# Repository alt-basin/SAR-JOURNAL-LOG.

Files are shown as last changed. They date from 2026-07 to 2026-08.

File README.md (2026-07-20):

# Sensor-Controlled Thermal Mapping for Search and Rescue Operations (SCOUT) 

**Editor's Note**

- This project is still a work in progress. Software development has not yet begun. While I have studied how the hardware components interface with one another, I have not yet started the implementation phase. My current priority is designing the custom PCB. Since the PCB layout depends on the exact physical dimensions of the drone frame and its components, obtaining the hardware is a necessary first step to ensure accurate measurements, footprints, and component placement.

  If you have any questions or suggestions regarding the project, feel free to reach out. As development progresses, I will publish the PCB design files, complete development logs, and software documentation in this repository for others to reference, learn from, or reuse. All project materials will be openly shared with proper attribution. The PCB design will also include my personal signature as a mark of authorship.

**For Forge Reviewers**

- I hope the components listed in the Bill of Materials (BOM) can be funded so I can verify their physical dimensions before completing the PCB design. This will help ensure accurate footprints, proper component placement, and minimize alignment issues during assembly.

  I will cover the cost of PCB fabrication myself and will upload the completed PCB design files to this GitHub repository once they are finalized.

**Current Status**

* Learning and implementing an Extended Kalman Filter (EKF)
* Researching autonomous navigation and localization methods
* Preparing documentation and development logs

---

  ### PROJECT OVERVIEW:
#### Main Description

- The goal of this project is to develop a prototype autonomous-capable Search and Rescue (SAR) drone intended for outdoor disaster scenarios such as earthquakes, landslides, and floods.

  The system is designed to assist search operations by capturing aerial data and detecting heat signatures using a thermal camera. This capability may help identify potential heat sources associated with human presence in outdoor environments with reduced visibility, including nighttime conditions, smoke, or partially obstructed areas.

  The drone combines thermal imaging, optical flow, an Inertial Measurement Unit (IMU), and distance sensors to support stable flight and estimate its motion during operation. The project serves as a demonstration of how low-cost robotic aerial systems can contribute to SAR-oriented exploration, environmental monitoring, and situational awareness.

#### Reason for Build

- This project originated from hardware that was initially intended for a larger cargo-drone design being developed for a future robotics competition. During the planning stage, it became apparent that the selected components were not suitable for the intended cargo-drone requirements.

   Rather than discarding or selling the components, the decision was made to repurpose them into a Search and Rescue drone prototype that could also serve as a school research project.

   The project provides an opportunity to gain practical experience in drone development, autonomous navigation, sensor integration, state estimation, and embedded systems while making effective use of existing hardware resources.

---

### HARDWARE OVERVIEW:
#### Hardware list:
*sensor + electronics selection:*
<table border="1" cellpadding="10" cellspacing="0" style="border-collapse: collapse; width: 100%; font-family: Arial, sans-serif;">
  <thead>
    <tr style="background-color: #1a1a2e; color: white;">
      <th>Component</th>
      <th>Function</th>
      <th>Purpose in the Project</th>
      <th>Link</th>
    </tr>
  </thead>
  <tbody>
    <tr>
      <td><strong>ICM-20602</strong></td>
      <td>Measures linear acceleration and angular velocity using a 3-axis accelerometer and 3-axis gyroscope.</td>
      <td>Provides orientation and motion data for flight stabilization, attitude estimation, and autonomous navigation.</td>
      <td><a href="https://shopee.ph/product/1541768712/47054536700" target="_blank">View Product</a></td>
    </tr>
    <tr style="background-color: #f2f2f2;">
      <td><strong>PMW3901</strong></td>
      <td>Tracks the movement of the ground beneath the drone using optical flow technology.</td>
      <td>Estimates horizontal velocity and position, allowing stable flight in GPS-denied indoor environments.</td>
      <td><a href="https://shopee.ph/product/1538176896/43426280197" target="_blank">View Product</a></td>
    </tr>
    <tr>
      <td><strong>VL53L1X</strong></td>
      <td>Uses a laser Time-of-Flight (ToF) system to accurately measure the distance to nearby surfaces.</td>
      <td>Maintains altitude, enables vertical positioning, and assists in autonomous takeoff and landing.</td>
      <td><a href="https://shopee.ph/product/1032050598/22974977435" target="_blank">View Product</a></td>
    </tr>
    <tr style="background-color: #f2f2f2;">
      <td><strong>MLX90640BAA</strong></td>
      <td>Captures a 32×24 thermal image by measuring infrared radiation emitted from objects.</td>
      <td>Detects heat signatures, performs thermal mapping, and assists in locating people or heat sources during search-and-rescue operations.</td>
      <td><a href="https://shopee.ph/product/1622086447/43117260078" target="_blank">View Product</a></td>
    </tr>
    <tr>
      <td><strong>ESP32-S3-WROOM-1 (N16R8)</strong></td>
      <td>Processes sensor data, executes control algorithms, and manages communication between all hardware components.</td>
      <td>Acts as the drone's primary controller, performing sensor fusion (EKF), flight control, autonomous navigation, telemetry, and system coordination.</td>
      <td>—</td>
    </tr>
  </tbody>
</table>

*Airframe and Power System*
<table border="1" cellpadding="10" cellspacing="0" style="border-collapse: collapse; width: 100%; font-family: Arial, sans-serif;">
  <thead>
    <tr style="background-color: #1a1a2e; color: white;">
      <th>Component</th>
      <th>Function</th>
      <th>Purpose in the Project</th>
      <th>Link</th>
    </tr>
  </thead>
  <tbody>
    <tr>
      <td><strong>JMT X4 310mm Frame</strong></td>
      <td>Provides the structural framework for mounting and protecting all electronic and mechanical components.</td>
      <td>Serves as the drone's main chassis, ensuring stability, durability, and proper component placement during flight.</td>
      <td><a href="https://shopee.ph/product/936939040/18971876269" target="_blank">View Product</a></td>
    </tr>
    <tr style="background-color: #f2f2f2;">
      <td><strong>Uangel X2807 1300KV Motor</strong></td>
      <td>Converts electrical energy into rotational motion to spin the propellers and generate thrust.</td>
      <td>Provides the lift and maneuverability required for stable flight, navigation, and autonomous operation.</td>
      <td><a href="https://shopee.ph/product/53025630/22476350635" target="_blank">View Product</a></td>
    </tr>
    <tr>
      <td><strong>55A 4-in-1 ESC</strong></td>
      <td>Controls the speed and direction of each brushless motor by regulating electrical power from the battery.</td>
      <td>Enables precise motor control for stable flight, attitude correction, and autonomous maneuvers.</td>
      <td><a href="https://shopee.ph/product/709543365/28338653787" target="_blank">View Product</a></td>
    </tr>
    <tr style="background-color: #f2f2f2;">
      <td><strong>6S 5200mAh 60C LiPo Battery</strong></td>
      <td>Supplies electrical power to the motors, flight controller, sensors, and other onboard electronics.</td>
      <td>Acts as the drone's primary power source, providing sufficient energy for flight operations and autonomous missions.</td>
      <td>—</td>
    </tr>
    <tr style="background-color: #f2f2f2;">
      <td><strong>PRO MINI560</strong></td>
      <td> is a <strong>DC-DC buck converte</strong> that efficiently reduces a higher input voltage to a stable lower output voltage for electronic devices.</td>
      <td>Acts as the drone's primary power source, providing sufficient energy for flight operations and autonomous missions.</td>
      <td><a href="https://shopee.ph/product/1400942760/28687044552" target="_blank">View Product</a></td>
    </tr>
    <tr style="background-color: #f2f2f2;">
      <td><strong>7040 Gemfan Tri-Blade</strong></td>
      <td> Converts the motor's rotational force into thrust, allowing the UAV to generate lift and maneuver during flight.</td>
      <td> Provides stable and efficient lift for the SCOUT UAV while carrying its onboard sensors and thermal camera during autonomous missions.</td>
      <td>—</td>
    </tr>
  </tbody>
</table>

#### Schematic:

<table>
  <tr>
    <!-- Left Column -->
    <td width="55%" valign="top">

<h2>Hardware Connections</h2>

<table>
  <thead>
    <tr>
      <th>Component</th>
      <th>Connection</th>
    </tr>
  </thead>
  <tbody>
    <tr>
      <td><strong>VL53L1X</strong></td>
      <td>SDA → GPIO 8<br>SCL → GPIO 9</td>
    </tr>
    <tr>
      <td><strong>MLX90640BAA</strong></td>
      <td>SDA → GPIO 8<br>SCL → GPIO 9</td>
    </tr>
    <tr>
      <td><strong>ICM-20602</strong></td>
      <td>SAO/SDO → GPIO 13<br>SDA/SDI → GPIO 11<br>SCL/SPC → GPIO 12</td>
    </tr>
    <tr>
      <td><strong>PMW3901</strong></td>
      <td>MISO → GPIO 13<br>CLK → GPIO 12<br>MOSI → GPIO 11<br>CS → GPIO 10</td>
    </tr>
    <tr>
      <td><strong>45A 4-in-1 ESC</strong></td>
      <td>
        M1 → GPIO 4<br>
        M2 → GPIO 5<br>
        M3 → GPIO 6<br>
        M4 → GPIO 7<br>
        GND → IN−<br>
        VCC → IN+
      </td>
    </tr>
  </tbody>
</table>

> **Note:** The VL53L1X and MLX90640BAA share the same I²C bus (GPIO 8 & 9), while the ICM-20602 and PMW3901 share the SPI bus (GPIO 11–13).

</td>

<!-- Right Column -->
<td width="45%" align="center" valign="top">



<br><br>

<i>Figure 1. Current hardware wiring diagram.</i>

</td>
</tr>
</table>

[Drone Schematic](SCHEMATIC/GENERAL.SCHEMATIC.v1.png)

---

### SYSTEM OVERVIEW:

#### Perception system:

- This subsystem provides the drone’s perception and navigation capability for indoor search and rescue mapping. It combines motion sensing, position estimation, altitude measurement, and thermal imaging to allow controlled flight and environmental scanning in a confined area (2m × 2m).
  
<table>
    <thead>
        <tr>
            <th>Component</th>
            <th>Type</th>
            <th>Purpose</th>
        </tr>
    </thead>
    <tbody>
        <tr>
            <td>ICM-20602</td>
            <td>IMU (Inertial Measurement Unit)</td>
            <td>Will be used as the sensor to determine the drone’s yaw, roll, and pitch, as well as its movement using the built-in accelerometer.</td>
        </tr>
        <tr>
            <td>PMW3901</td>
            <td>Optical Flow Sensor</td>
            <td>Will be used to determine the drone’s velocity in mid-air.</td>
        </tr>
        <tr>
            <td>VL53L1X + lid</td>
            <td>Time-of-Flight (ToF) Distance Sensor</td>
            <td>This will serve as the main sensor for measuring the drone’s altitude. However, this sensor is weaker outdoors, so testing and demonstrations will be conducted indoors.</td>
        </tr>
        <tr>
            <td>MLX90640BAA</td>
            <td>Thermal Infrared Camera</td>
            <td>This will be used to capture thermal images for mapping the environment.</td>
        </tr>
  </tbody>
</table>

#### **Control system:**

&emsp; *closed-loop system:*
- This part of the the subgroup measures the raw output of the sensors and filters them, allowing for smooth control.
<table>
    <thead>
        <tr>
            <th>Component</th>
            <th>Kalman Filter Category</th>
            <th>Reason</th>
        </tr>
    </thead>
    <tbody>
        <tr>
            <td>ICM-20602</td>
            <td>Extended Kalman Filter (EKF)</td>
            <td>Provides acceleration and angular velocity measurements used to predict the drone's state. Required for nonlinear attitude estimation.</td>
        </tr>
        <tr>
            <td>PMW3901</td>
            <td>Extended Kalman Filter (EKF)</td>
            <td>Provides optical flow used to correct velocity estimates. Depends on altitude and orientation, making the model nonlinear.</td>
        </tr>
        <tr>
            <td>VL53L1X</td>
            <td>Extended Kalman Filter (EKF)</td>
            <td>Provides range measurements for altitude estimation. Requires tilt compensation (roll/pitch), making the measurement nonlinear.</td>
        </tr>
        <tr>
            <td>MLX90640</td>
            <td>Not part of EKF</td>
            <td>Used for thermal imaging and environment mapping. Operates independently from state estimation.</td>
        </tr>
    </tbody>
</table>

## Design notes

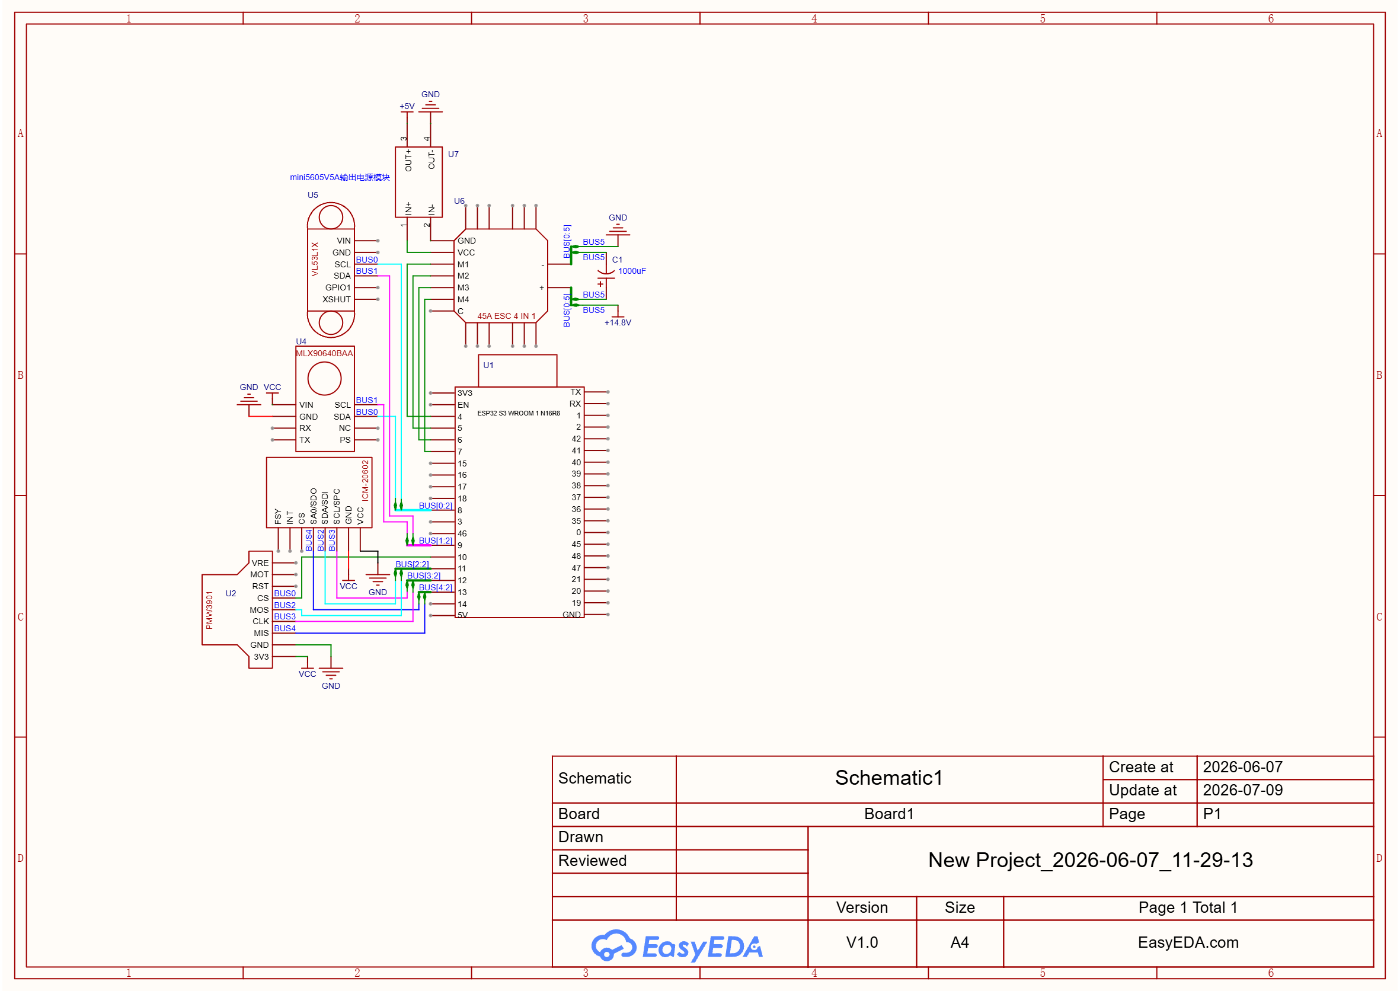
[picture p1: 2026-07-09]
SCH_Schematic1_1-P1_2026-07-09.png

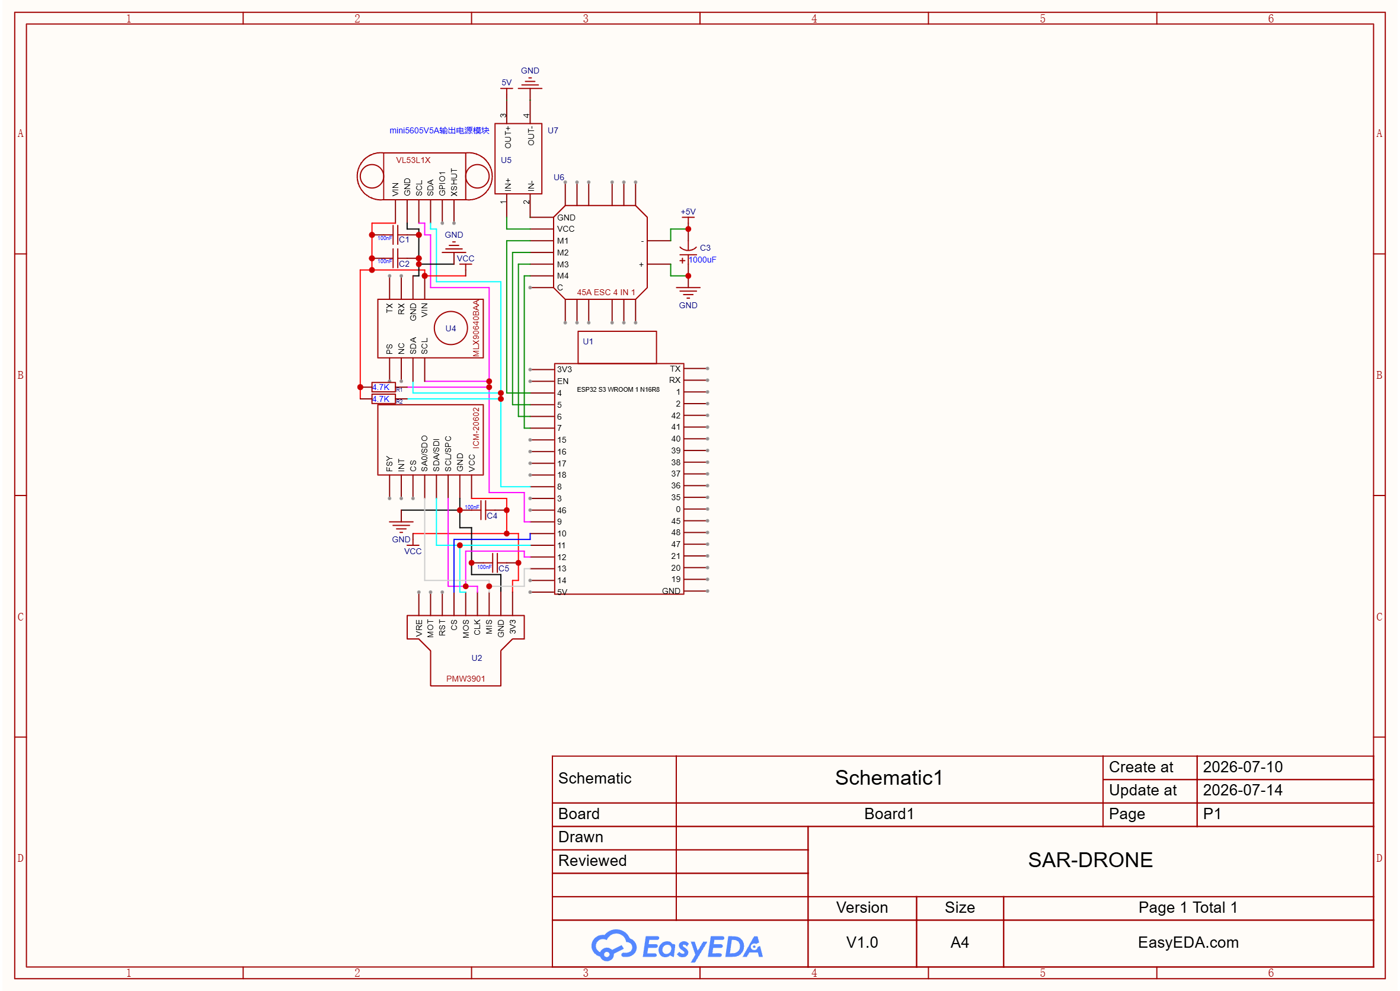
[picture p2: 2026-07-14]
SCHEMATIC/GENERAL.SCHEMATIC.V1.png

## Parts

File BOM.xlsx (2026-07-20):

Component | Quantity | Retail price | Link
ICM-20602 | 1 | 294 | https://shopee.ph/product/1541768712/47054536700
PMW3901 | 1 | 412 | https://shopee.ph/product/1538176896/43426280197
VL53L1X + LID | 1 | 408 | https://shopee.ph/product/1032050598/22974977435
MLX90640BAA | 1 | 2375 | https://shopee.ph/product/1622086447/43117260078
55A ESC 4-IN-1 | 1 | 1545 | https://shopee.ph/product/709543365/28338653787
PRO MINI560 - 5V | 1 | 105 | https://shopee.ph/product/1137847711/24580460137
Uangel X2807 1300kv (4x) | 1 | 2380 | https://shopee.ph/product/779642846/25478721198
 | Total: | 7519.00

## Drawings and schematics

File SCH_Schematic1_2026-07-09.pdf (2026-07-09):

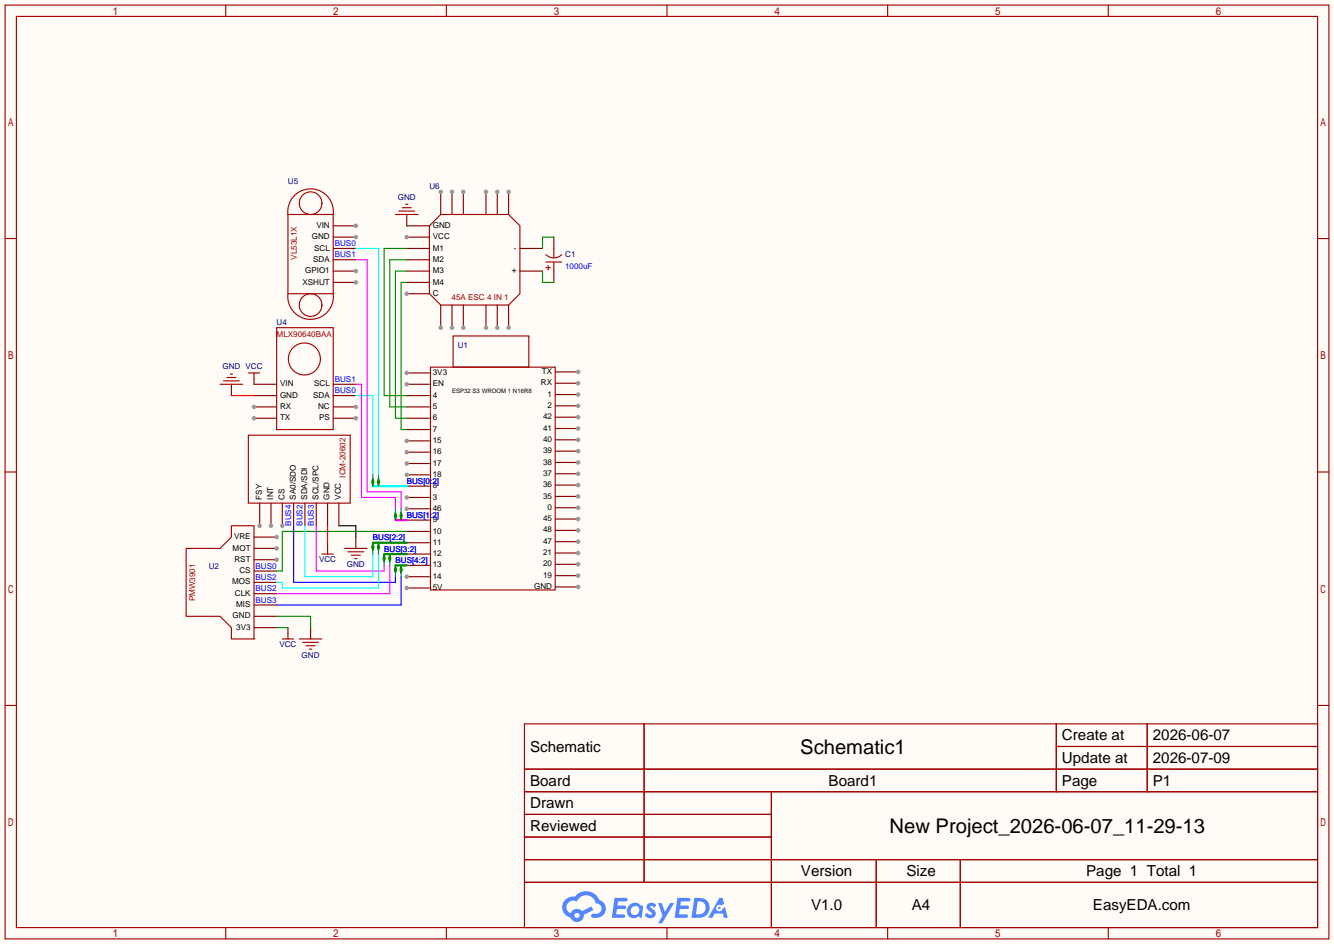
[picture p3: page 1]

Schematic | Schematic1 | Create at | 2026-06-07

Update at | 2026-07-09

Board | Board1 | Page | P1
Drawn | | New Project_2026-06-07_11-29-13
Reviewed

Version | Size | Page 1 Total 1
V1.0 | A4 | EasyEDA.com

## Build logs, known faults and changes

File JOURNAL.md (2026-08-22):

# DEVLOG #001: INTRODUCTION

 **Total Time Spent: 5 minutes** pre-repo work
 
 first ever log for the drone, i have already created the schematic, though i will need to continue creating the <br> drones
 pcb to hold the parts which may take a long time. So lets start by discussing the parts of the drone.

  im currently using a 
   - JMT X4 310MM X4M310L
   - Uangel X2807 1300Kv
   - 6s 5200mah XT60

7df4a46b-1eed-4ec3-b51c-5aaf73f997b2
e7acb897-12b7-4c4b-9561-0c1f1995207d

---
# DEVLOG #002: INTRO TO SCHEMATIC

 **Total Time Spent: 1 hour** pre-repo work

   ### SENSORS:
   
  - Below me is the schematic for the drone, which includes the parts needed for it to be full automated, so lets start one by one.
    for this dorone i will be using a ESP32-S3-WROOM-N16R8-1 as the flight control, and i will be using a 45A esc 4-in-1.
    
 
 
<table>
    <thead>
        <tr>
            <th>Component</th>
            <th>Type</th>
            <th>Purpose</th>
            <th>Link</th>
        </tr>
    </thead>
    <tbody>
        <tr>
            <td>MPU-6050</td>
            <td>IMU (Inertial Measurement Unit)</td>
            <td>Measures angular velocity and acceleration for estimating the drone's orientation and movement.</td>
            <td><a href="https://shopee.ph/product/580325202/25288429666">Product Link</a></td>
        </tr>
        <tr>
            <td>PMW3901</td>
            <td>Optical Flow Sensor</td>
            <td>Measures relative ground movement to estimate horizontal velocity and position changes.</td>
            <td><a href="https://shopee.ph/product/1538176896/43426280197">Product Link</a></td>
        </tr>
        <tr>
            <td>VL53L1X + Lid</td>
            <td>Time-of-Flight (ToF) Distance Sensor</td>
            <td>Measures the distance to the ground, providing altitude data for low-altitude indoor flight.</td>
            <td><a href="https://shopee.ph/product/1032050598/22974977435">Product Link</a></td>
        </tr>
        <tr>
            <td>MLX90640BAA</td>
            <td>Thermal Infrared Camera</td>
            <td>Captures thermal images for heat-source detection and thermal environment mapping.</td>
            <td><a href="https://shopee.ph/product/56540719/23154817594">Product Link</a></td>
        </tr>
        <tr>
            <td>45A 4-in-1 ESC</td>
            <td>Electronic Speed Controller</td>
            <td>Controls the speed of the brushless motors and distributes power from the battery.</td>
            <td><a href="https://shopee.ph/product/933050849/26220013460">Product Link</a></td>
        </tr>
        <tr>
            <td>4S 3200mAh 60C LiPo</td>
            <td>Lithium Polymer Battery</td>
            <td>Supplies electrical power to the drone's flight and sensing systems.</td>
            <td><a href="https://shopee.ph/product/1729536151/57358540563">Product Link</a></td>
        </tr>
    </tbody>
</table>

---
# DEVLOG #003: DRONE FRAME 

 **Total Time Spent: 17 minutes** 

 - The drone frame assembly was completed after the M3 nuts arrived. Below is a showcase of the finished frame from multiple angles.
  
  c05a2e44-0346-4d8f-9d85-8e693a4ecb37
51f45b0d-6c06-419b-8082-c667ce248333
b290c748-67dc-41cf-a960-94b504ee50dd

---
# DEVLOG #004: INTRODUCTION FOR BMI323

 **Total Time Spent: 5 minutes**

 - I decided to switch from the MPU6050 to a better IMU, the BMI323. This is mainly because it has lower drift and improved overall performance. I also considered using an ICM-series IMU, but most online stores currently do not have it available.

- The main difference between the two is their sensor performance and accuracy, which includes improvements in noise levels, stability, and motion tracking reliability in the BMI323 compared to the MPU6050. 

| Feature | MPU6050 | BMI323 |
| --- | --- | --- |
| Gyro noise density | ~0.005–0.01 °/s/√Hz | ~0.003 °/s/√Hz (lower = better) |
| Accelerometer noise | ~400 µg/√Hz | ~80–120 µg/√Hz |
| Gyro range | ±250 to ±2000 °/s | ±125 to ±2000 °/s (configurable, cleaner output) |
| Accelerometer range | ±2g to ±16g | ±2g to ±16g |
| Bias instability (gyro drift) | ~10–20 °/hr (worse in practice) | ~2–5 °/hr (much better) |
| Output resolution | 16-bit | 16–24 bit effective processing |
| Sample rate | up to 1 kHz | up to 6.4 kHz (depends config) |
| Power consumption | ~3.9 mA | ~0.8–1.5 mA (more efficient) |



---
# DEVLOG #005: NEW SYMBOL AND SCHEMATIC

**Total Time Spent: 10 minutes**

 - So i just created the new schematic for the drone which included the new IMU (BMI323).
   so the reason why I didnt do this yesterday is because i had assignments, and also i was lazy.

   it took around 4 mins to create the new symbol for the imu since i was trying to find the exact board model
   in a datasheet though i found the model by a youtube video. Which also described how to use it.

  
  

https://github.com/alt-basin/SAR-JOURNAL-LOG./blob/main/Schematics%2BPCB/Schematic_drone.pdf

---

# DEVLOG #006: MEASUREMENTS FOR PCB

**Total Time Spent: 26 mins 28 seconds**

- I decided to measure the drone frame (shown below) so I can use it as a reference for the PCB's shape, which will host the ESP32-S3-WROOM-1, IMU (Inertial   Measurement Unit), and other components.

  Right now, I am only preparing the measurements for the PCB since it will be mounted directly onto the frame. I am also waiting for the sensors to arrive so I can measure their pin layouts and dimensions accurately. I believe it is better to rely on measurements taken from the actual physical components rather than using dimensions from online sources.

  Here are the measurements.

  34cc6814-a46b-4476-9909-0267edcaa080
  341fd21e-3ca5-4c1e-b4bd-874106287189

 - I just wanted to show this to you since I currently have assignments to work on, and I won't be able to create the <br> actual measurements in a 3D model yet. I may have to work on it during the weekend.

---

# DEVLOG #007: UPDATE FOR REPO AND NEW SENSOR

**Total Time Spent: 1 hour 29 mins 54 seconds**

- So since I dont have any assignments today, i decided to create a data table for each sensor. So you could know whats the capabilities, while doing so I realized that my current imu (which is BMI323), is weak. Not that its fully weak but for testing that uses autonomous programming, this would be a problem.

  Then i asked gpt for potential sensors that are better than the current (BMI323) and recommended me to use and ICM-42688-P, which is better over all. The main problem wasnt cost as i have it covered, the main problem is the market availability. Each shopping app basically have this type of sensor, the problem was that it was all out of stock.

**6:27 pm**

- I was talking with Gpt about the sensors to find the common and cheapest, which landed me on the ICM-20602. so comparing this with the current bmi323, here are the data table. Now even though it may just be like a point different from a bmi, i only want to switch as the bmi323 isnt really popular.

  now that i have decided what kind of sensor i will use, i should probably change the BOM first, then i will start on creating the new schematic again.
  i should probably just add the data tables for the sensors tommorow.

| Specification | BMI323 |  | ICM-20602 |
|---|---|---|---|
| Sensor Type | 6-Axis IMU | = | 6-Axis IMU |
| Accelerometer Range | ±2g, ±4g, ±8g, ±16g | = | ±2g, ±4g, ±8g, ±16g |
| Gyroscope Range | **±125, ±250, ±500, ±1000, ±2000 °/s** | > | *±250, ±500, ±1000, ±2000 °/s* |
| Resolution | 16-bit | = | 16-bit |
| Gyro Noise Density | *~0.007 °/s/√Hz* | < | **0.004 °/s/√Hz** |
| Accel Noise Density | *~180 µg/√Hz* | < | **100 µg/√Hz** |
| Max Gyro ODR | *6.4 kHz* | < | **8 kHz** |
| Max Accel ODR | **6.4 kHz** | > | *4 kHz* |
| FIFO Size | **2 KB** | > | *1 KB* |
| Interfaces | **SPI, I²C, I3C** | > | *SPI, I²C* |
| Supply Voltage | **1.71–3.6 V** | > | *1.71–3.45 V* |
| Power Consumption | **Lower** | > | *Higher* |
| Package Size | **2.5 × 3.0 mm** | > | *3.0 × 3.0 mm* |
| Release Era | **Modern** | > | *Older* |
| Drone Usage | *Limited* | < | **Widely Used** |
| ESP32 Compatibility | Yes | = | Yes |

28f02160-13c6-4550-bb51-76e5383b8505

**8:05 pm**

- Here is the thing the schematic. i only keep chagning the schematic so i could have a visual guideline for the pcb.




https://github.com/alt-basin/SAR-JOURNAL-LOG./blob/main/BOM.xlsx <br>
https://github.com/alt-basin/SAR-JOURNAL-LOG./blob/main/SCHEMATIC/SCHEMATIC.pdf

- hello its me again, now im not actually saying that the ICM 20602 is better than the BMI323, just that the specs arent really built for an automated drone. Even though the bmi wins by 8 that doesnt automatically guarentee that the imu its great. just that its for other projects not for mine.

---

# DEVLOG #008: FOOTPRINT

**Total Time Spent: 4 hours**

 - Hello! It's been a while since my last update because I've been swamped with schoolwork. During my free time, I decided to work on creating the PCB footprints for the custom board I'm designing.

   At the moment, the PCB isn't fully complete. I still need to add the through-hole solder pads so the board can be connected to the components properly. I wasn't able to accurately track the total amount of time I spent on this task since I was constantly switching between EasyEDA and Google Docs for documentation and planning. However, I'd estimate that I spent around **4 hours** working on it.




 - so probably im just going to add this to the pcb development file, but soon i will replace it with a more refined version with the through-hole solder pads.
   I re-synced all of my project files and didn't realize it would reset their timestamps.

   also be minded this is my first time making a footprint, so i dont really know if its bad or not

---

# DEVLOG #009: idk

**Total Time Spent: 10 mins**

- While working on my PCB design yesterday, I realized that I had been using copper traces instead of the board outline. I corrected that mistake, so here's the updated version.

   I'm also writing today's devlog a bit earlier because I forgot to do it yesterday, and I really want to get to sleep early since I only got around three hours of sleep. I also had to attend the birthday celebration of a family friend today, which took up most of my evening.
   
   
   
   <br>
   
   

- also, pcbdoc.

---

# DEVLOG #010: SCHEMATIC REFINING

**Total time spent: 4 mins**

- I also updated the schematic by adding a Mini560 buck converter. This allows the ESC to supply a stable regulated voltage to the microcontroller instead of powering it directly from the battery. The buck converter steps down the battery voltage to a level that is safe for the microcontroller and other low voltage electronics, improving the reliability and safety of the power distribution system.



---

# DEVLOG #011: Motor Mounting Issue and Assembly Lesson

**Total time spent: 3 Minute**

5b88c2b6-0f94-4790-9b57-e16fb2b95f28

*Figure X. Example of motor winding damage observed after assembly.
This image shows one example of the damage found on the brushless motors. While this motor shows visible copper wire damage, several other motors exhibited deeper cuts that were difficult to properly capture through photography due to their location and severity.*

- For future iterations, motor mounting depth will be checked before installation, and appropriate screw lengths will be selected to prevent interference with internal components.

  During the early assembly phase of the drone prototype, the motor mounting screws used were found to be longer than required. This caused the screws to contact the internal motor components, resulting in visible damage to the copper winding area of the brushless motors.

  Initial inspection was performed by comparing the phase resistance of each motor using a multimeter. The readings remained consistent across the motors, indicating that electrical continuity was maintained. However, this incident highlighted the importance of verifying hardware dimensions and screw length before mechanical assembly.

# DEVLOG #012: ADDRESSING THE DELAY

**Total time spent: 3 Minutes**

- Hello! The reason progress on the robot has been slower than expected is that I've been working on a detailed project analysis that will be reviewed by my teacher as part of my research project.

  Since my groupmates are not very experienced with robotics, I considered switching to a simpler project, the smartwatch prototype, which would require less complex programming. However, that project also presents a challenge. Its primary function is detecting hazardous gases, such as carbon monoxide, so I need to build a proof of concept by testing the sensors. To do that properly, I need to consult with an engineer from our main campus.

  Because of this, I am currently preparing the project overview and technical analysis to compare both projects and determine which one is the most feasible to pursue for our research.

  

---

# DEVLOG #013: HEADSUP

**Total time spent: 1 Minute**

- Hello again, just be reminded I had to re-sync the entries because i had to add parsed time "Total time spent: 3 Minutes", since i thought it should be "duration: ". okay good bye.

  

---

# DEVLOG #014: FENDERS FOR THE DRONE

 **Total time spent: 34 Minutes 23 Seonconds**
 
**6:32 pm**




*Figure X shows an example of Joseph Fraser's prop guard design. This design is particularly useful during testing because it helps protect the propellers from accidental impacts with walls, obstacles, or other objects during indoor flight. It also improves safety by reducing the risk of damage to both the drone and its surroundings, making it well suited for prototype development and testing.*

- Hello! A while back, while working on my SAR drone, I realized that the entire research is mainly intended for indoor use. Because of that, I decided that adding prop guards would make the drone much safer during testing.

  At first, I planned to design and create my own prop guards. However, after considering my current schedule, I realized that it would take time away from more important parts of the project. I still need to revise the research paper, especially since the project overview will be reviewed by an engineer, so I want to make sure I use my time wisely.

  Because of this, I decided to use an open source prop guard design instead. This allows me to focus on completing the drone itself while still improving safety for indoor operation.

  The prop guard design I will be using was created by **Joseph Fraser**. You can find it here:

https://www.printables.com/model/465552-7-75-inch-fpv-drone-prop-guards-and-bumpers/files

- I would like to give full credit to Joseph Fraser for creating and sharing this design with the community.

**8:51 pm**



*Figure X showcases the current status of the schematic*

- While refining the Project Overview, I made a few revisions to the schematic. In the updated version, you'll notice that I connected the CS pin of the ICM-20602 to GPIO32 after realizing there would be a pin conflict between two of the sensors.

  I also decided to change one of the drone's major components: the battery. Instead of using the original 4S 3300 mAh 60C LiPo battery, I switched to a 6S 5200 mAh 60C LiPo battery. While this configuration results in a shorter estimated flight time, it is the more practical and cost effective option. Since I already own the 6S battery, I only need to purchase a compatible ESC, whereas the 4S configuration would require purchasing both a new battery and an ESC. This change allows me to reduce the overall project cost while maintaining compatibility with the selected propulsion system.

---

# DEVLOG #015: UPDATE

 **Total time spent: 2 hours 30 minute**

<table>
 <tbody>
  <tr>
   <td>
    
   </td>
  </tr> 
  <tr>
   <td>
- Hello! you might be wondering why there isnt much activity on this repository, thats because last week we had our title defense. I was preparing my groups research paper (Chapter 1 and 2) about the robot, i had to do most of the work since i was the leader. and during this, i had incidents that happen during re arranging the drone frame
   </td>
  </tr>
 </tbody>
</table>

**3:48 pm**

<table>
  <thead>
    <tr>
      <th>Document for the Incident</th>
      <th>Figure 1</th>
    </tr>
  </thead>

  <tbody>
    <tr>
      <td>

During the assembly and modification of the drone, the frame had to be rearranged to accommodate the other components. While securing one of the BLDC (Brushless DC) motors, one of the M3 bolts became difficult to remove and its threads were also damaged. The bolt eventually became stuck, preventing the M3 Allen driver from properly engaging with it.

Several methods were attempted to remove the bolt:

1. <b>Rubber band method</b> – A rubber band was placed between the bolt and the Allen driver to provide additional grip. However, the rubber band was too weak and eventually tore without removing the bolt.

2. <b>Pliers</b> – Pliers were used to grip the bolt, but this only caused scratches and cosmetic damage to the frame.

3. <b>M3 Allen driver</b> – The Allen driver was used again in an attempt to loosen the bolt, but the bolt head became further damaged, making it increasingly difficult to remove.

4. <b>Side-cutting pliers</b> – As a final attempt, side pliers were used to remove the stuck bolt. Unfortunately, the attempt resulted in further damage to the drone frame.

Because the bolt could no longer be removed without causing additional damage, the affected part of the frame was damaged beyond practical use. A replacement frame was therefore purchased.
      </td>
      <td>
        Damaged drone frame arm
        <br><br>
        <i>Figure 1. Damaged drone frame arm where the BLDC motor was mounted.</i>
      </td>
    </tr>
    
  </tbody>
</table>

**4:18 pm**

<table>
 <thead>
  <tr>
   <td>
   770883777_1440110324676812_8643678499963505015_n
   </td>
  </tr>
  <tr>
   <td>
    Here is the new design of the drone frame. I combined the two frame designs to create a stronger and more durable build. The new frame features thicker arms and a thicker base plate, providing better structural support and making it more resistant to stress and damage during assembly and flight.
   </td>
  </tr>
 </thead>
</table>

<table>
 <thead>
  <tr>
   <td>
    I forgot to mention that I decided to look for another model for the drone fenders because the previous design was too expensive to print. I found a printing service that charges only around ₱270 per arm, compared to the previous store's ₱900 per arm, which significantly reduces the overall cost.

The new fender model is from Printables and was created by Duck Vault. Credit goes to the original creator for the design.

<a href="https://www.printables.com/model/1248120-propeller-guards-for-mk4-7-inch-drone">Click here to view the model!</a>
   </td>
   <td>
    772352717_1229023113631590_6512868241765153967_n
   </td>
   <td>
    773981383_2539140863223956_5410443673940220438_n
   </td>
  </tr>
 </thead>
</table>

---

# DEVLOG #015: HARDWARE UPDATE

 **Total Time Spent: 14 minutes**

<table>
 <thead>
 <tr>
  <td>
   
  </td>
 </tr>
 <tr>
  <td>
 - Hello!, you may notice that the format of Devlog #014 is weird, thats because i used tables on the repo which wasnt properly formated on the website but yeah.
  </td>
 </tr>
 </thead>
</table>

<table>
 <tbody>
  <tr>
   <td>
    Soo i while back, i decided to optimize the drone to better perform both outdoors and indoors, Soooo i started fidnding sensors that can be used to replcae the current ones (Icm 20602, vl53l1x, and pmw3901). since the teacher told me that because the drone will be operating on an SAR operation, its logical to make the drone also fly outdoors. 
    
   </td>
  </tr>
  <tr>
   <td>
    773166296_28166715982948938_3323641777399844770_n
   </td>
  </tr>
  <tr>
   <td>
     1.) the first change i did was changing Vl53L1X and PMW3901, i did some research until i realized that i already have a strong sensor that being the
        MTF-02P. You can also notice that the sensor is super small, i even place a ruler so you could see how small it is. so the reason why im going to use this 
        mostly because it outclasses the previous sensors.
   </td>
  </tr>
  <tr>
   <td>
  <table>
  <tr>
    <th>Parameter</th>
    <th>VL53L1X</th>
    <th>PMW3901</th>
    <th>MTF-02P</th>
  </tr>
  <tr>
    <td>Distance error</td>
    <td>±20 mm (dark) / ±25 mm (ambient light)</td>
    <td>N/A</td>
    <td>2 cm (&lt;2m) / 1.5% (&gt;2m)</td>
  </tr>
  <tr>
    <td>Repeatability</td>
    <td>±0.15–1%</td>
    <td>N/A</td>
    <td>Not specified</td>
  </tr>
  <tr>
    <td>Min. working distance</td>
    <td>4 cm</td>
    <td>80 mm</td>
    <td>2 cm (ranging) / 8 cm (flow)</td>
  </tr>
  <tr>
    <td>Max range</td>
    <td>400 cm</td>
    <td>∞</td>
    <td>6 m</td>
  </tr>
  <tr>
    <td>FOV</td>
    <td>27°</td>
    <td>42°</td>
    <td>42° / 2°</td>
  </tr>
  <tr>
    <td>Max speed</td>
    <td>N/A</td>
    <td>7.4 rad/s</td>
    <td>7 m/s @ 1m</td>
  </tr>
  <tr>
    <td>Ambient light min.</td>
    <td>—</td>
    <td>110 lux</td>
    <td>60 lux</td>
  </tr>
  <tr>
    <td>Operating temp</td>
    <td>−20 to 85°C</td>
    <td>0 to 40°C</td>
    <td>−20 to 85°C</td>
  </tr>
  <tr>
    <td>Interface</td>
    <td>I²C, 400 kHz</td>
    <td>SPI, 2 MHz</td>
    <td>UART</td>
  </tr>
  </table>
    </td>
  </tr>
  <tr>
   <td>
    2.) I decided to switch the ICM-20602 with a stronger one, which would be icm 42688 p since its stronger, thats pretty much it.
   </td>
  </tr>
  <tr>
   <td>
    <table border="1" cellpadding="6" cellspacing="0">
  <tr>
    <th>Parameter</th>
    <th>ICM-20602</th>
    <th>ICM-42688-P</th>
  </tr>
  <tr>
    <td>Gyro noise density</td>
    <td>4 mdps/√Hz</td>
    <td>2.8 mdps/√Hz</td>
  </tr>
  <tr>
    <td>Gyro sensitivity error</td>
    <td>±1%</td>
    <td>±0.5%</td>
  </tr>
  <tr>
    <td>Gyro ZRO (zero-rate offset)</td>
    <td>±1 dps</td>
    <td>±0.5 dps</td>
  </tr>
  <tr>
    <td>Gyro cross-axis sensitivity</td>
    <td>±1%</td>
    <td>±1.25%</td>
  </tr>
  <tr>
    <td>Accel noise density</td>
    <td>100 µg/√Hz</td>
    <td>65–70 µg/√Hz</td>
  </tr>
  <tr>
    <td>Accel sensitivity error</td>
    <td>±1%</td>
    <td>±0.5%</td>
  </tr>
  <tr>
    <td>Accel zero-G offset</td>
    <td>±25 mg (component) / ±40 mg (board)</td>
    <td>±20 mg</td>
  </tr>
  <tr>
    <td>Accel cross-axis sensitivity</td>
    <td>±1%</td>
    <td>±1%</td>
  </tr>
  <tr>
    <td>Operating temp</td>
    <td>−40 to 85°C</td>
    <td>−40 to 85°C</td>
  </tr>
  <tr>
    <td>Interface</td>
    <td>I²C 400kHz / SPI 10MHz</td>
    <td>I²C 1MHz / I3C 12.5MHz / SPI 24MHz</td>
  </tr>
</table>
   </td>
  </tr>
 </tbody>
</table>

- I wont be editing the Readme for a while since i have allot of work to do, since today is assynchronous i have allot of assignments to do. So thats it for now!

# DEVLOG #015: PCB Revisions or idk

 **Total Time Spent: 4 hours 34 minutes**

 -Hi! decided to create the pcb today since i got bored. I basically started with the upper part. also be reminded that this is my FIRST TIME ever wiring and adding components (such as thhe JST male 1mm that you will see). so i hope this wont get you mad or anything.

 also even though the design might look like relatively simple, i had to do multiple revisions which took time, tomorrow i have like research paper activities to do and next week, or maybe todays week (22/08/2026) we would have our exams.
 
 <table>
  <tbody>
   <tr>
    <td>
     
     
     
    </td>
   </tr>
   <tr>
    <td>
    The PCB above is the custom board I made for the upper part of the drone, which will house the IMU or Inertial Measurement Unit. It is responsible for securely holding the component while also allowing us to connect it to the main PCB without using male jumper wires. Instead, we will use a JST 1.0 mm 6-pin connector, which makes the connection cleaner, more secure, and more organized. I also chose the JST connector because it gives the overall drone a more compact and professional look.
     <br>
     <br>
     Originally, this PCB was supposed to have a different design and layout. It was initially planned to look more like this:
     <br>
     <br>
     
     <br>
     <br>
     This is a very early prototype of the PCB. This design was originally meant to house the ESP32, which acts as the microcontroller, along with the Mini560 power module. However, I realized that I would also need to fit the other navigation sensors and the thermal camera onto this small plate, which would make the PCB too cramped and difficult to work with. It would look something like this:
     <br>
     <br>
     
    </td>
   </tr>
   <tr>
    <td>
    775183281_2063177181237373_5287926560353745309_n
    </td>
   </tr>
   <tr>
    <td>
     So here is the visual look on were i will place that part, i circled it with red.
    </td>
   </tr>

   <tr>
    <td>
     
    </td>
   </tr>
   <tr>
    <td>
     
    </td>
   </tr>
   <tr>
    <td>
     
    </td>
   </tr>
   <tr>
    <td>
     Now this is relatively a simple piece, i didnt really do much here because i didnt use professional techniques (using formulas) because i was in a hurry, so you may see some mistakes. This is also my first time so i hope you wont criticize or sum.
    </td>
   </tr>
  </tbody>
 </table>

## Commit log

2026-06-13 Create SCHEMATIC
2026-06-13 Update SCHEMATIC
2026-06-13 Rename Screenshot 2026-06-11 200743.png to schematic1
2026-06-25 Fix link to Bill of Materials in JOURNAL.md
    Updated the link to the Bill of Materials in JOURNAL.md.
2026-07-01 Revise PCB design journal entry
    Updated journal entry with additional details about PCB design progress and time estimation.
2026-07-01 PCB development
    [FOOTPRINT FOR BOOTOM PART V1.pcbdoc, FOOTPRINT FOR UPPER PART V1.pcbdoc]
2026-07-01 Rename FOOTPRINT FOR BOOTOM PART V1.pcbdoc to PCB development/FOOTPRINT FOR BOOTOM PART V1.pcbdoc
    [FOOTPRINT FOR BOOTOM PART V1.pcbdoc]
2026-07-01 Rename PCB file for consistency
    [fp bottom V1.pcbdoc]
2026-07-01 Rename PCB development/FOOTPRINT FOR UPPER PART V1.pcbdoc to PCB development/Upper pcb/V1.pcbdoc
    [V1.pcbdoc]
2026-07-01 Rename V1.pcbdoc to fp upper V1.pcbdoc
    [fp upper V1.pcbdoc]
2026-07-05 Rename FOOTPRINT FOR BOOTOM PART V1 (1).pcbdoc to PCB development/FOOTPRINT FOR BOOTOM PART V1 (1).pcbdoc
    [FOOTPRINT FOR BOOTOM PART V1 (1).pcbdoc]
2026-07-05 Rename FOOTPRINT FOR UPPER PART V1 (1).pcbdoc to PCB development/FOOTPRINT FOR UPPER PART V1 (1).pcbdoc
    [FOOTPRINT FOR UPPER PART V1 (1).pcbdoc]
2026-07-05 Rename PCB development/FOOTPRINT FOR UPPER PART V1 (1).pcbdoc to PCB development/UPPER PCB/UPPER PART V1 (1).pcbdoc
    [UPPER PART V1 (1).pcbdoc]
2026-07-05 Rename PCB development/FOOTPRINT FOR BOOTOM PART V1 (1).pcbdoc to PCB development/BOTTOM PCB/BOTTOM PART V1 (1).pcbdoc
    [BOTTOM PART V1 (1).pcbdoc]
2026-07-05 Rename SCHEMATIC/SCHEMATIC.pdf to PCB development/SCHEMATIC/SCHEMATIC v1.pdf
2026-07-05 Rename PCB development/SCHEMATIC/SCHEMATIC v1.pdf to SCHEMATIC/GENERAL SCHEMATIC v1.pdf
2026-07-05 Rename PCB development/BOTTOM PCB/BOTTOM PART V1 (1).pcbdoc to PCB development/BOTTOM PCB/FOOTPRINT/BOTTOM PART V1 (1).pcbdoc
    [BOTTOM PART V1 (1).pcbdoc]
2026-07-05 Rename PCB development/UPPER PCB/UPPER PART V1 (1).pcbdoc to PCB development/UPPER PCB/FOOTPRINT/UPPER PART V1 (1).pcbdoc
    [UPPER PART V1 (1).pcbdoc]
2026-07-05 Create BOTTOM SCHEMATIC
2026-07-05 Create UPPER SCHEMATIC
2026-07-05 Rename PCB development/CAD/FENDER to CAD/FENDER
2026-07-08 Rename GENERAL SCHEMATIC v1.pdf to GENERAL.SCHEMATIC.v1.pdf
2026-07-08 Rename SCH_Schematic1_2026-07-08 (1).pdf to SCHEMATIC/GENERAL.SCHEMATIC.V1.pdf
2026-07-20 Rename CAD/FENDER to CAD/FENDERS/Quick note
2026-07-20 Create CAD
2026-07-20 Update C7 Prop Bumper L V6.4.stl
2026-07-20 Rename C7 Prop Bumper R V6.4.stl to CAD/C7 Prop Bumper R V6.4.stl
    [C7 Prop Bumper R V6.4.stl]
2026-07-20 Rename FENDER to C7 Prop Bumber R v6.4.stl
    [C7 Prop Bumber R v6.4.stl]
